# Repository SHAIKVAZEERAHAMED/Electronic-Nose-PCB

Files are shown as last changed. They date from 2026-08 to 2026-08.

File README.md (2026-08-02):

# Electronic Nose System

A compact 14-channel MEMS-based Electronic Nose (E-Nose) platform designed for multi-gas sensing applications. The system integrates analog signal acquisition, dual-microcontroller processing, heater control, and battery-powered operation on a custom-designed PCB developed using KiCad.

---

## Overview

The Electronic Nose System is a modular hardware platform designed to interface with fourteen MEMS gas sensors for detecting a wide range of volatile organic compounds (VOCs) and hazardous gases. The design combines dedicated analog front-end circuits, a dual-microcontroller architecture, and an efficient power management subsystem into a compact printed circuit board.

The project focuses on hardware architecture, PCB implementation, and modular subsystem design to support future gas classification and pattern recognition algorithms.

---

## Key Features

- 14-channel MEMS gas sensor array
- ESP32-S3 WROOM 1 N16 main controller
- RP2040 dedicated PWM co-processor
- Configurable analog front-end
- Battery-powered operation
- Dual heater voltage rails (1.8 V and 2.5 V)
- BME680 environmental sensing
- KiCad 9.0.7 PCB design
- Modular hardware architecture

---

## System Architecture

```text
                    +----------------------+
                    |   MEMS Gas Sensors   |
                    +----------+-----------+
                               |
                               v
                    +----------------------+
                    |  Analog Front End    |
                    +----------+-----------+
                               ^
                               |
                              SPI
                               |
                               v
                    +----------------------+
                    |   ESP32-S3 (Master)  |
                    +----+--+---------+----+
                         |  ^         |
                         |  |         |
                      UART SPI       I²C/ADC
                         |  |         |
                         v  v         v
                  +--------------+  BME680
                  |    RP2040    |
                  +------+-------+
                         |
                         v
                +------------------+
                |  Heater Driver   |
                +--------+---------+
                         |
                         v
                +------------------+
                |  MEMS Heaters    |
                +------------------+

          Power Management supplies all modules
```

<p align="center">
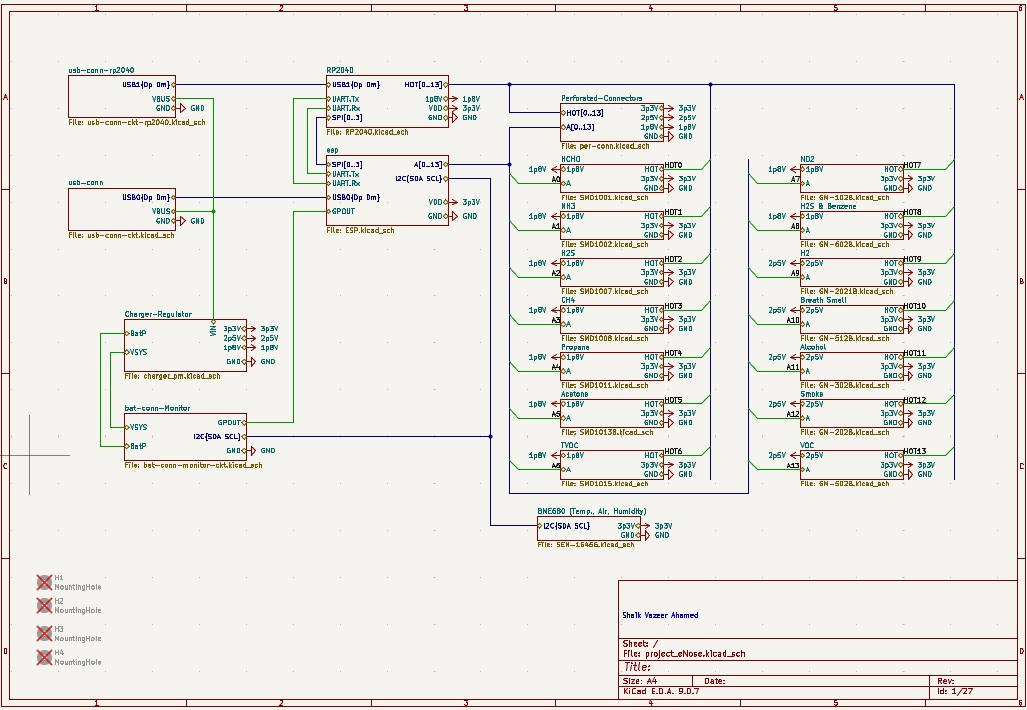
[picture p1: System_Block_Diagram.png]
  
</p>
---
---

## PCB Layout

### Top View

<p align="center">
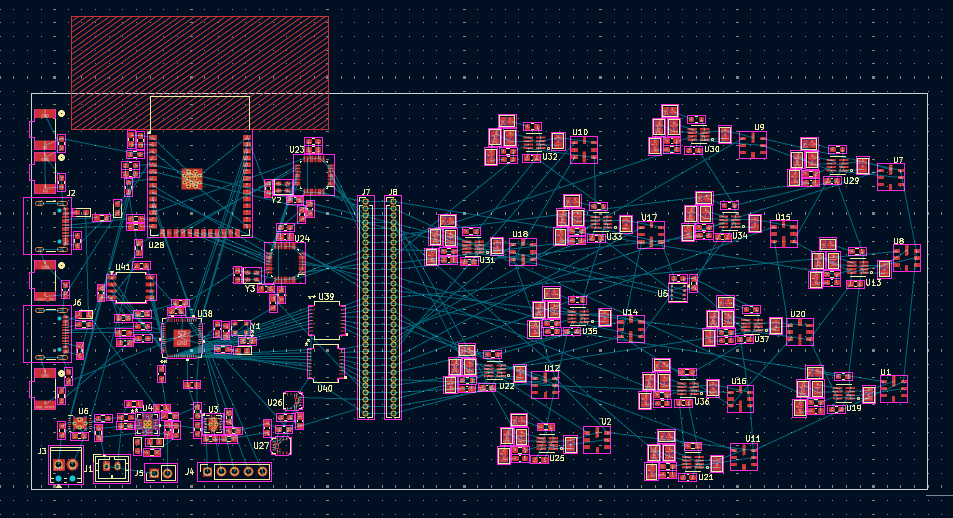
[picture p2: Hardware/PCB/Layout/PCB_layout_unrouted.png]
  
</p>

### 3D View

<p align="center">
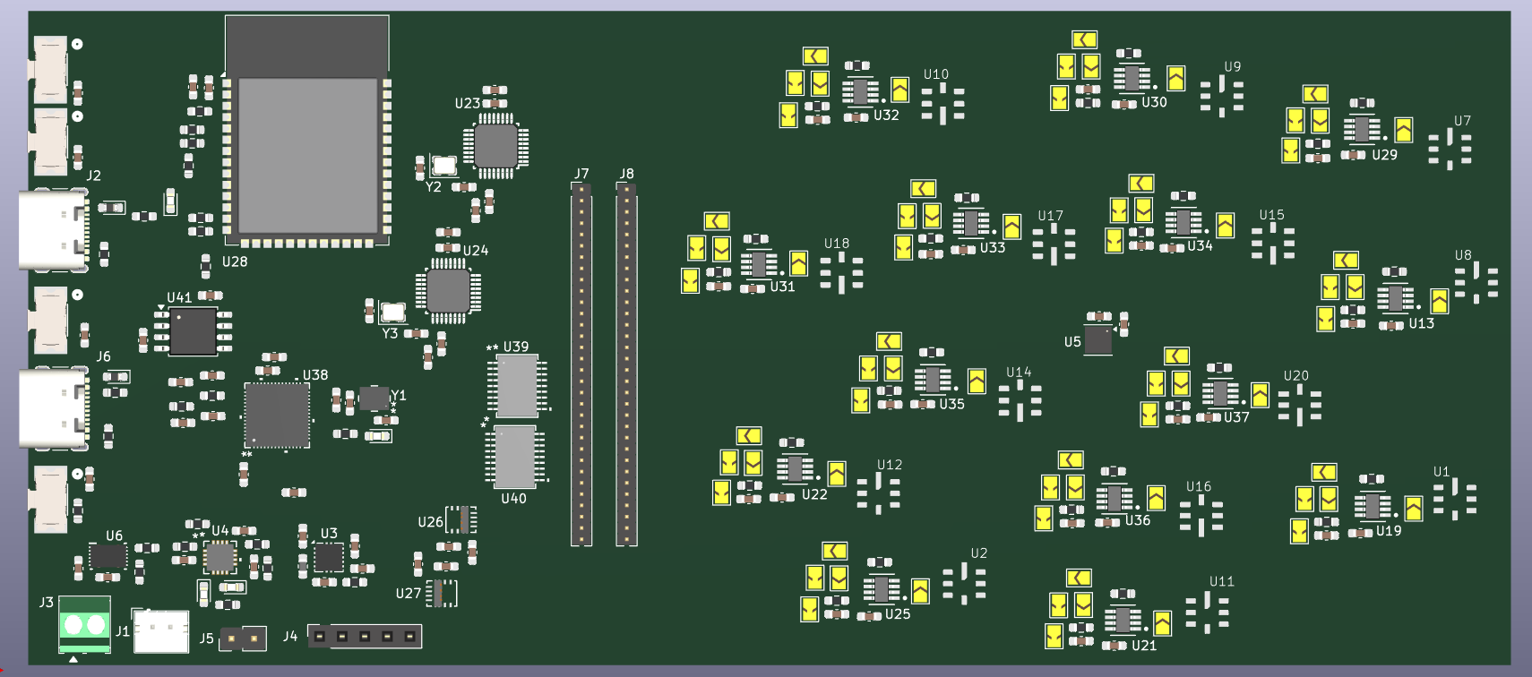
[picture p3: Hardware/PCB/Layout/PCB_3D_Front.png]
  
</p>

<p align="center">
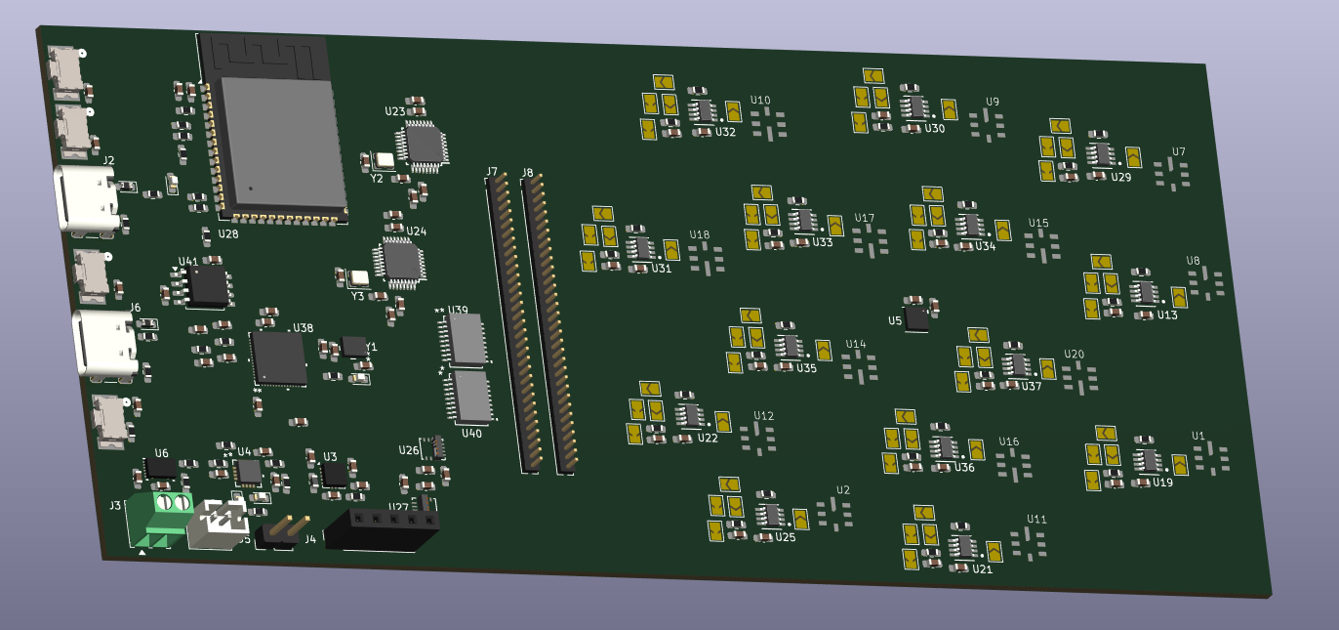
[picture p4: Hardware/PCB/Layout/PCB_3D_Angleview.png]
  
</p>

---

## Hardware Specifications

| Component | Description |
|---|---|
| Gas Sensors | 14 MEMS Gas Sensors |
| Main Controller | ESP32-S3 WROOM 1 N16 |
| PWM Controller | RP2040 |
| Heater Driver | TBD62083AFNG |
| Environmental Sensor | BME680 |
| Analog Front End | TLV9152 |
| PCB Software | KiCad 9.0.7 |
| Power Source | Rechargeable Li-ion Battery |

---

## Repository Structure

```text
Electronic-Nose-PCB
│
├── Hardware
│   ├── Sensors
│   ├── Analog_Front_End
│   ├── ESP32-S3
│   ├── RP2040
│   ├── Power_Management
│   ├── PCB
│   └── KiCad_Project
│
├── Documentation
├── Datasheets
└── README.md
```
---

## Hardware

The hardware design is divided into modular subsystems:

- MEMS Gas Sensor Array
- Analog Front-End
- ESP32-S3 Processing Unit
- RP2040 PWM Controller
- Heater Driver
- Battery Management
- PCB Layout

---

## Software

| Tool | Purpose |
|---|---|
| KiCad 9.0.7 | PCB Design |
| GitHub | Version Control |

---

## Project Status

🚧 Under Development

Current progress:

- ✅ System Architecture
- ✅ Schematic Design
- ⏳ PCB Layout
- ⏳ PCB Fabrication
- ⏳ Hardware Testing
- ⏳ Firmware Development

---

## License

This project is intended for academic and research purposes.

---

## Acknowledgment

This work was carried out at the International Institute of Information Technology Bangalore (IIIT Bangalore) under the guidance of Prof. Kurian Polachan. Technical guidance and discussions from Prof. David Aleklett Kadish and David Cuartielles (Malmö University and Arduino Co-founder) are gratefully acknowledged.

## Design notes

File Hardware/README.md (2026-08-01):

# Hardware

This directory contains the complete hardware design of the Electronic Nose PCB.

The hardware is organized into functional subsystems to simplify design, development, testing, and future maintenance.

## Hardware Organization

| Folder | Description |
|---|---|
| Sensors | MEMS gas sensor array and sensor interface |
| Analog_Front_End | Signal conditioning circuits including RC filters and operational amplifiers |
| ESP32-S3 | Main controller responsible for sensor acquisition and communication |
| RP2040 | Dedicated PWM controller for MEMS heater control |
| Power_Management | Battery charger, fuel gauge, voltage regulators, and power distribution |
| PCB | PCB layouts, fabrication outputs, and 3D models |
| KiCad_Project | Complete KiCad project files |

## Design Software

- KiCad 9.0.7

## Hardware Overview

The Electronic Nose PCB integrates a fourteen-channel MEMS gas sensor array, analog front-end circuits, dual microcontrollers (ESP32-S3 and RP2040), and a dedicated power management subsystem into a compact modular platform.

Each subsystem is documented separately within its respective directory.

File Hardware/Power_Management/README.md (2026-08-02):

# Power Management

This directory contains the power management circuitry of the Electronic Nose hardware.

## Overview

The power management subsystem supplies regulated voltages to the analog, digital, and sensor heater circuits. It is designed to support battery-powered operation while providing stable and efficient power distribution across the entire system.

## Main Functions

- Battery charging
- Battery voltage monitoring
- Fuel gauging
- Voltage regulation
- Power distribution

## Power Architecture

The system operates from a rechargeable lithium-ion battery. Dedicated power management circuits generate multiple regulated voltage rails required by the different subsystems.

| Voltage Rail | Purpose |
|---|---|
| 3.3 V | ESP32-S3, RP2040, BME680, analog circuitry |
| 2.5 V | MEMS sensor heaters |
| 1.8 V | MEMS sensor heaters |

## Main Components

| Component | Function |
|---|---|
| Battery Charger IC | Battery charging |
| Fuel Gauge IC | Battery monitoring |
| Buck Converter | 2.5 V supply |
| Buck Converter | 1.8 V supply |
| Buck Boost Converter | 3.3 V supply |

### Per-rail power summary

| Rail | Sensors | Peak current (all on) | Max heater power |
|---|---|---|---|
| 1.8 V | 9 | ~179 mA | ≤ 321 mW |
| 2.5 V | 5 | ~100 mA | ≤ 250 mW |
| **Total** | **14** | | **≤ 571 mW** |

Peak current and power figures are calculated from the rated maximum heater power at the rail voltage (I = P_max / V_rail). Actual in-use power will be lower, as not all sensors will be active simultaneously during temperature modulation sequences, and most sensors draw less than their rated maximum.

---

## Why Two Voltage Rails Are Required

All sensors in this array are MEMS resistive hot-plate sensors. Their heater elements are calibrated at a specific voltage which sets the hot-plate operating temperature, and therefore the sensitivity profile of the sensing material. Running a sensor at the wrong heater voltage shifts its operating temperature, degrading both sensitivity and cross-selectivity characteristics.

### Why not run all sensors from a single rail with PWM?

A common simplification is to power all sensors from the higher 2.5 V rail and use PWM with a lower duty cycle to reduce the effective drive for the 1.8 V sensors. This does not work correctly for resistive heaters, for the following reason.

A resistive heater responds to **average power**, not average voltage. Average power is proportional to V²:

```
P = V_rms² / R
```

With PWM at duty cycle D from a 2.5 V source:

```
V_avg = 2.5 × D
V_rms = 2.5 × √D
P_avg = (2.5)² × D / R
```

To set `V_avg = 1.8 V`, you need `D = 1.8 / 2.5 = 72%`. But this gives:

```
V_rms = 2.5 × √0.72 = 2.12 V
P_avg ∝ (2.12)² = 4.49   (vs 1.8² = 3.24 for true 1.8 V DC)
```

The heater would receive **38% more power** than intended, running significantly hotter than specified. To match the power of a 1.8 V DC supply, the duty cycle must be set to:

```
D = (1.8 / 2.5)² = 51.8%
```

— which gives a mean voltage of only ~1.3 V, not 1.8 V. The "average voltage = rated voltage" shortcut is incorrect for resistive loads.

Additionally, sensors in both groups prohibit exceeding 120 mW heater dissipation. With heater resistance tolerance of 60–100 Ω and 2.5 V applied during PWM ON-phases, instantaneous power can approach 104 mW — uncomfortably close to the limit with no margin for component variation.

Two separate regulated voltage rails eliminate this ambiguity and ensure each sensor operates within its characterised, calibrated conditions.

---

## Why Buck Converters at This Scale

### The efficiency argument is significant across ~570 mW of heater load

With a total heater load of ~571 mW, LDO losses from a 3.3 V input rail would be substantial:

| Rail | LDO efficiency (from 3.3 V) | Wasted power |
|---|---|---|
| 1.8 V (321 mW load) | 55% | ~262 mW wasted |
| 2.5 V (250 mW load) | 76% | ~79 mW wasted |

Total LDO waste would be ~341 mW — more than half the useful heater power, dissipated as heat on the PCB. Buck converters operating at 85–90% efficiency reduce total waste to roughly **60–85 mW**, a saving of ~260 mW.

### Thermal contamination of measurements

The wasted regulator power does not simply reduce battery runtime — it heats the PCB. All sensors in this array show strong temperature dependence: the Winsen GM-series datasheets show Rs/Rs₀ varying by factors of 2–3 across -20 °C to +50 °C. Heat dissipated by voltage regulators near the sensor array introduces a temperature offset and drift into all measurements. Buck converters, being far more efficient, dissipate far less heat locally.

## Design Considerations

- Independent power rails for digital and heater circuits
- Stable voltage supply for analog measurements
- Efficient battery-powered operation
- Low-noise power distribution
- Proper decoupling capacitors near integrated circuits

## Folder Contents

This folder will contain:

- Power management schematic
- Battery charger circuit
- Fuel gauge circuit
- Buck converter circuits

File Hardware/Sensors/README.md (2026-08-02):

# MEMS Gas Sensors

This directory contains the MEMS gas sensor array used in the Electronic Nose system.

## Overview

The Electronic Nose employs a fourteen-channel MEMS-based gas sensor array to detect a broad range of volatile organic compounds (VOCs) and hazardous gases. The sensors were selected to provide diverse sensing characteristics, enabling improved gas discrimination through pattern recognition techniques.

## Sensor Inventory and Rail Assignments

All 14 sensors, their heater voltages, maximum heater power, and assigned rails are listed below.

| Sensor | Manufacturer | Target gas | V_H | P_H (max) | Rail |
|---|---|---|-----|---|---|
| GM-102B | Winsen | NO₂ | 1.8 V ±0.1 V | ≤ 40 mW | 1.8 V |
| SMD1001 | IDM/Huiwen | Formaldehyde | 1.8 V ±0.05 V | ≤ 36 mW | 1.8 V |
| SMD1002 | IDM/Huiwen | Ammonia (NH₃) | 1.8 V ±0.05 V | ≤ 36 mW | 1.8 V |
| SMD1007 | IDM/Huiwen | Hydrogen sulfide (H₂S) | 1.8 V ±0.05 V | ≤ 36 mW | 1.8 V |
| SMD1008 | IDM/Huiwen | Methane (CH₄) | 1.8 V ±0.05 V | ≤ 30 mW | 1.8 V |
| SMD1011 | IDM/Huiwen | Propane (C₃H₈) | 1.8 V ±0.05 V | ≤ 30 mW | 1.8 V |
| SMD1013B | IDM/Huiwen | TVOC | 1.8 V ±0.1 V | ≤ 43 mW | 1.8 V |
| SMD1015 | IDM/Huiwen | Acetone | 1.8 V ±0.1 V | ≤ 30 mW | 1.8 V |
| GM-602B | Winsen | H₂S & benzene | 1.9 V ±0.1 V | ≤ 40 mW | 1.8 V† |
| GM-202B | Winsen | Smoke/alcohol | 2.5 V ±0.1 V | ≤ 50 mW | 2.5 V |
| GM-302B | Winsen | Ethanol | 2.5 V ±0.1 V | ≤ 50 mW | 2.5 V |
| GM-502B | Winsen | VOC | 2.5 V ±0.1 V | ≤ 50 mW | 2.5 V |
| GM-512B | Winsen | H₂S/alcohol/acetone | 2.5 V ±0.1 V | ≤ 50 mW | 2.5 V |
| GMV-2021B | Winsen | Hydrogen (H₂) | 2.5 V ±0.1 V | ≤ 50 mW | 2.5 V |

**†** The GM-602B is rated 1.9 V ±0.1 V, giving an operating range of 1.8 V to 2.0 V. Running it at 1.8 V places it at the lower bound of its specified tolerance. Heater power will be slightly less than at the 1.9 V nominal (by a factor of (1.8/1.9)² ≈ 90%), which is conservative and within the ≤ 40 mW limit. Sensitivity curves in the GM-602B datasheet are characterised at 1.9 V; response function will be marginally different at 1.8 V but the sensor is not damaged or out-of-spec. This grouping avoids the need for a dedicated third rail.

## Features

- Fourteen MEMS gas sensors
- Two independent heater voltage rails (1.8 V and 2.5 V)
- Individual analog output for each sensor
- PWM-based heater control through the RP2040

## Folder Contents

This folder will contain:

- Sensor schematics
- Sensor placement diagrams
- PCB images
- Sensor documentation

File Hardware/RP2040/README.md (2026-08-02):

# RP2040

This directory contains the RP2040 subsystem used in the Electronic Nose hardware.

## Overview

The RP2040 serves as a dedicated co-processor responsible for generating high-frequency PWM signals for independent control of the MEMS gas sensor heaters. Offloading PWM generation from the ESP32-S3 reduces computational overhead while providing precise timing and accurate heater control. The generated PWM signals are applied to a DMOS driver, which supplies the required current to the sensor heaters.

## Main Responsibilities

- High-frequency PWM generation
- Independent heater control
- Communication with the ESP32-S3 through UART
- Control of the TBD62083AFNG DMOS driver

## Heater Control

Each MEMS gas sensor incorporates an integrated micro-heater that requires controlled power to achieve the desired operating temperature. The RP2040 generates configurable PWM signals, which are routed to the **TBD62083AFNG DMOS driver**. The DMOS driver provides the necessary current-driving capability to switch the heater supply, enabling reliable and efficient heater operation.

## Interfaces

| Interface | Connected Device |
|---|---|
| UART & SPI | ESP32-S3 |
| GPIO | TBD62083AFNG DMOS Driver |
| PWM | MEMS Sensor Heaters (via DMOS Driver) |

## Features

- Dual-core ARM Cortex-M0+ processor
- Hardware PWM peripherals
- Precise timing generation
- Low-power operation
- Independent heater control

## Design Rationale

The RP2040 was selected because it provides multiple hardware PWM channels with accurate timing, making it well suited for controlling the MEMS sensor heaters. Since the RP2040 GPIOs cannot directly drive the heater load, the PWM outputs (10 KHz frequency) are interfaced with the **TBD62083AFNG DMOS driver**, which provides the required current-driving capability for the heater circuits. Separating heater control from the primary processing tasks improves overall system performance and allows the ESP32-S3 to focus on sensor acquisition, communication, and system management.

## Signal Flow

```text
ESP32-S3
     │
   UART
     │
     ▼
RP2040
     │
   PWM Outputs
     │
     ▼
TBD62083AFNG
DMOS Driver
     │
     ▼
MEMS Sensor Heaters
```

## Components

| Component | Description |
|---|---|
| RP2040 | PWM co-processor |
| TBD62083AFNG | 8-channel DMOS sink driver |
| UART | Communication with ESP32-S3 |
| PWM Outputs | Heater control signals |

## Folder Contents

This folder contains:

- RP2040 schematic
- UART interface
- PWM generation circuit
- DMOS driver interface

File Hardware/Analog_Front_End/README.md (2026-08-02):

# Analog Front End

This directory contains the analog front-end circuitry used to interface the MEMS gas sensors with the data acquisition system of the Electronic Nose.

## Overview

Each MEMS gas sensor produces an analog voltage proportional to the detected gas concentration. Before digitization, the sensor output passes through an analog front-end designed to improve signal quality, provide configurable amplification, and ensure accurate analog-to-digital conversion.

The analog front-end consists of:

- RC low-pass filter
- TLV9152 rail-to-rail operational amplifier
- Configurable gain selection using solder jumpers
- ADS131M08 multi-channel Analog-to-Digital Converter (ADC)
- SPI interface to the ESP32-S3

## Low-Pass Filter

A first-order RC low-pass filter with a cutoff frequency of approximately **7 kHz** is used to suppress high-frequency noise before amplification and digitization.

## Operational Amplifier

The TLV9152 operational amplifier supports two operating modes:

### Voltage Follower

- Unity gain
- High input impedance
- Low output impedance

### Non-Inverting Amplifier

- Gain selectable using Registers
- Suitable for low-level sensor signals

The low output impedance of the amplifier minimizes signal degradation caused by long PCB traces and provides a stable input to the ADC.

## Analog-to-Digital Conversion

The conditioned analog outputs from the gas sensors are sampled using the **ADS131M08**, an eight-channel, high-resolution analog-to-digital converter. The external ADC provides improved measurement accuracy and lower noise compared with the ESP32-S3 internal ADC. Digitized sensor data are transferred to the ESP32-S3 through the SPI interface for further processing.

## Signal Flow

```text
MEMS Gas Sensor
        │
        ▼
RC Low-Pass Filter (7 kHz)
        │
        ▼
TLV9152 Operational Amplifier
        │
        ▼
Gain Selection Jumpers
        │
        ▼
ADS131M08 ADC
        │
      SPI Bus
        │
        ▼
ESP32-S3
```

## Components

| Component | Description |
|---|---|
| TLV9152 | Rail-to-rail operational amplifier |
| RC Network | 7 kHz low-pass filter |
| Solder Jumpers | Gain configuration |
| ADS131M08 | 24-bit multi-channel ADC |
| SPI Interface | Communication between ADC and ESP32-S3 |

## Folder Contents

This folder contains:

- Analog front-end schematics
- ADC interface circuit

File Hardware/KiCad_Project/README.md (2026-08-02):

# KiCad Project

This directory contains the complete KiCad project files for the Electronic Nose hardware.

## Overview

The Electronic Nose PCB was designed using **KiCad 9.0.7**. This folder includes all project files required to open, edit, verify, and manufacture the PCB.

## Software Version

- KiCad 9.0.7

## Project Files

| File | Description |
|---|---|
| *.kicad_pro | KiCad project file |
| *.kicad_sch | Complete schematic |
| *.kicad_pcb | PCB layout |

## Design Features

- Multi-sheet schematic
- Fourteen-channel MEMS gas sensor array
- Dual microcontroller architecture
- Analog front-end circuitry
- Power management subsystem
- Single-layer PCB layout
- Design Rule Check (DRC) in progress
- Electrical Rule Check (ERC) verified

## How to Open

1. Install **KiCad 9.0.7** or later.
2. Open the `.kicad_pro` file.
3. Use the Schematic Editor to view the circuit design.
4. Use the PCB Editor to inspect or modify the layout.

## Folder Contents

This folder will contain:

- KiCad project
- Schematics
- PCB layout

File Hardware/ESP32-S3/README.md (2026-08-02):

# ESP32-S3

This directory contains the ESP32-S3 subsystem of the Electronic Nose hardware.

## Overview

The ESP32-S3 serves as the primary processing unit of the Electronic Nose system. It is responsible for acquiring sensor data, communicating with peripheral devices, and coordinating the overall operation of the system.

## Main Responsibilities

- Acquisition of analog signals from the MEMS gas sensors
- Communication with the RP2040 through UART and SPI
- Communication with the BME680 environmental sensor through I²C
- Battery monitoring
- System control and coordination
- Wireless communication (Wi-Fi / Bluetooth)

## Interfaces

| Interface | Connected Device |
|---|---|
| ADC | Analog Front End |
| UART | RP2040 |
| SPI | RP2040 |
| I²C | BME680 |
| GPIO | System peripherals |

## Features

- Dual-core Xtensa LX7 processor
- Integrated Wi-Fi and Bluetooth
- Multiple ADC channels
- UART, SPI, and I²C interfaces
- Low-power operation

## Folder Contents

This folder will contain:

- ESP32-S3 schematic
- Circuit diagrams

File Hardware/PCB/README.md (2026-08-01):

# Printed Circuit Board (PCB)

This directory contains the PCB layout, fabrication outputs, and mechanical design of the Electronic Nose system.

## Overview

The Electronic Nose hardware was implemented as a compact printed circuit board (PCB) designed using KiCad 9.0.7. The layout integrates the MEMS gas sensor array, analog front-end circuits, processing units, heater control circuitry, and power management subsystem into a single modular platform.

## PCB Features

- Compact PCB layout
- Fourteen-channel MEMS gas sensor array
- Modular subsystem placement
- Battery-powered operation
- Dedicated analog and digital sections
- Detachable sensor board
- Design optimized for future expansion

## PCB Design Considerations

The PCB layout was designed with emphasis on:

- Functional component grouping
- Short analog signal paths
- Efficient power distribution
- Stable ground connections
- Heater and signal isolation
- Manufacturability

## Board Contents

The PCB includes the following functional blocks:

- MEMS Gas Sensor Array
- Analog Front End
- ESP32-S3 Controller
- RP2040 PWM Controller
- Heater Driver
- Power Management
- Environmental Sensor

## Folder Contents

This folder will contain:

- PCB Top View
- PCB Bottom View
- 3D PCB Model
- Gerber Files
- Drill Files
- Manufacturing Outputs
- Assembly Drawings

## Directory Structure

```text
PCB/
├── Layout/
├── Gerbers/
├── Manufacturing/
```

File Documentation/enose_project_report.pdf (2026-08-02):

# Design and PCB Implementation of an Electronic Nose System

Shaik Vazeer Ahamed
Department of Electronics and Communication Engineering International Institute of Information Technology Bangalore Email: Shaik.Ahamed@iiitb.ac.in

Abstract—Electronic nose (e-nose) systems have gained significant attention for applications in environmental monitoring, industrial safety, healthcare, and food quality assessment due to their ability to detect and distinguish multiple gases. This paper presents the design and printed circuit board (PCB) implementation of a compact electronic nose system integrating a fourteen-channel gas sensor array with analog signal conditioning, power management, and embedded processing. The hardware architecture employs an ESP32-S3 microcontroller for system control and wireless communication, while an RP2040 microcontroller is incorporated to generate high-frequency pulse-width modulation (PWM) signals for independent sensor heater control. Dedicated analog front-end circuits were designed to condition the sensor outputs before data acquisition. A rechargeable battery management subsystem, multiple regulated power rails, and environmental sensing were integrated to enable reliable standalone operation. The PCB was designed using KiCad

### 9.0.7 with careful consideration of component placement, power

distribution, ground plane implementation, thermal management, and a detachable perforated sensor board to facilitate sensor replacement and future upgrades. The developed hardware provides a compact and modular platform suitable for multigas sensing applications and serves as a foundation for future gas identification and pattern recognition algorithms.
Index Terms—Electronic Nose, Gas Sensors, PCB Design, ESP32-S3, RP2040, Signal Conditioning, KiCad 9.0.7
I. INTRODUCTION
Electronic nose (e-nose) systems have emerged as an effective technology for detecting and distinguishing volatile compounds by employing an array of gas sensors combined with signal processing techniques. Unlike conventional gas detection systems that are designed to identify a single target gas, electronic noses utilize the collective response of multiple sensors to generate characteristic patterns for different gaseous environments. Owing to their versatility, e-nose systems have been widely investigated for applications including environmental monitoring, industrial safety, food quality assessment, agricultural monitoring, and healthcare diagnostics [1]–[3]. Recent advancements in low-power embedded systems and gas sensing technologies have enabled the development of compact and portable electronic nose platforms. In particular, temperature modulation and fast heater cycling have been shown to improve the selectivity and gas discrimination capability of MEMS metal-oxide gas sensors [1]–[3]. However, the integration of multiple gas sensors with their associated analog front-end circuits, heater control, power management, and embedded processing remains a significant hardware design challenge. Variations in sensor operating conditions, analog signal integrity, power distribution, and thermal effects must be carefully considered during both schematic development and printed circuit board (PCB) layout to ensure reliable system operation.
This work presents the design and PCB implementation of a compact electronic nose system capable of supporting a fourteen-channel gas sensor array. The proposed hardware integrates analog signal conditioning circuits, dedicated heater control, battery management, environmental sensing, and dual microcontroller architecture using the ESP32-S3 and RP2040. The system architecture was designed to provide modularity, efficient power distribution, and simplified sensor integration while maintaining a compact PCB layout suitable for standalone operation.
The PCB was developed using KiCad 9.0.7 with emphasis on component placement, power and ground distribution, thermal management, and the implementation of a detachable perforated sensor board to facilitate sensor replacement and future hardware expansion. The resulting hardware platform provides a flexible foundation for the development of electronic nose applications involving multi-gas sensing and subsequent pattern recognition.
The remainder of this paper is organized as follows. Section II presents the overall system architecture. Section III describes the hardware design, including the gas sensor array, analog signal conditioning circuits, processing units, and power management subsystem. Section IV discusses the PCB layout design and implementation. Section V presents the implementation results and design verification, while Section VI concludes the paper.

II. SYSTEM OVERVIEW

A. Overall System Architecture
Figure 1 illustrates the overall architecture of the proposed electronic nose system. The system integrates a fourteen-channel gas sensor array, analog signal conditioning circuits, dual microcontrollers, power management circuitry, and an environmental sensor on a custom-designed printed circuit board (PCB). The modular architecture was developed to provide reliable sensor interfacing, efficient power distribution, and simplified hardware integration.
The gas sensor array consists of fourteen MEMS-based gas sensors, each interfaced with an analog signal conditioning


Fig. 1: Overall system architecture.

circuit. The conditioned analog signals from the fourteen MEMS gas sensors are digitized using the ADS131M08 multi-channel analog-to-digital converter (ADC). The digitized sensor data are transferred to the ESP32-S3 through the SPI interface for further processing and wireless communication. An RP2040 microcontroller is incorporated as a dedicated co-processor to generate high-frequency pulse-width modulation (PWM) signals required for independent heater control of the gas sensors. Communication between the two controllers is achieved through standard digital communication interfaces. The power management subsystem includes a rechargeable battery, battery charging circuit, fuel gauge, and multiple regulated voltage rails to supply the various analog and digital components. In addition, a BME680 environmental sensor is integrated to monitor ambient temperature, humidity, and pressure, enabling environmental compensation during gas sensing. A detachable perforated sensor board is employed to simplify sensor replacement and facilitate future hardware modifications without affecting the main processing board.

B. Overall Architecture

III. HARDWARE DESIGN

A. MEMS Gas Sensor Array

The proposed electronic nose system employs a fourteen-channel MEMS-based gas sensor array to detect a broad range of volatile organic compounds (VOCs) and hazardous gases. MEMS gas sensors were selected due to their compact size, low power consumption, fast thermal response, and improved stability compared with conventional gas sensors. Each sensor incorporates an integrated micro-heater that maintains the sensing material at the required operating temperature.
To enable selective gas detection, sensors with different sensing characteristics were incorporated into the array. The diverse sensor responses provide characteristic signal patterns that can be utilized for subsequent gas identification algorithms. Table I summarizes the gas sensors used in the proposed system and their primary target gases.

TABLE I: MEMS Gas Sensors Used in the Proposed Electronic Nose

Sensor | Target Gas | Heater Voltage
SMD1001 SMD1002 SMD1007 SMD1008 SMD1011 SMD1013B SMD1015 GM-102B GM-202B GM-2021B GM-302B GM-502B GM-512B GM-602B | HCHO NH3 H2S Combustible Gases (CH4) Propane Acetone TVOC NO2 Smoke H2 Alcohol VOC Breath Odor H2S and Benzene | 1.8 V 1.8 V 1.8 V 1.8 V 1.8 V 1.8 V 1.8 V 1.8 V 2.5 V 2.5 V 2.5 V 2.5 V 2.5 V 1.8 V

In addition to the gas sensor array, a BME680 environmental sensor was integrated to measure ambient temperature, humidity, and pressure. These environmental parameters can be used for compensation during sensor calibration and gas sensing, thereby improving measurement consistency under varying operating conditions.

B. Signal Acquisition Circuit

Each MEMS gas sensor is interfaced with an identical signal acquisition circuit to ensure consistent signal conditioning before analog-to-digital conversion. As shown in Fig. 3 and Fig. 4, the sensor output is first passed through a first-order RC low-pass filter with a cutoff frequency of approximately 7 kHz. The filter suppresses high-frequency noise while preserving the low-frequency variations in the sensor response that are relevant for gas detection.
Following the low-pass filter, the conditioned signal is buffered using a TLV9152 rail-to-rail operational amplifier. The amplifier configuration can be selected through solder jumper pads, allowing the circuit to operate either as a voltage follower (unity-gain buffer) or as a non-inverting amplifier with adjustable gain. This configurable design provides flexibility for interfacing sensors with different output voltage ranges without requiring modifications to the PCB.
The operational amplifier also serves as an impedance buffer between the sensor and the analog-to-digital converter (ADC). Its high input impedance minimizes loading of the sensor, while its low output impedance reduces signal degradation caused by long PCB traces and improves the stability of the analog signal presented to the ADS131M08 analog-to-digital converter. The conditioned analog signals are digitized by the ADS131M08 ADC and transferred to the ESP32-S3 through the SPI interface.
C. Processing and Communication

The proposed electronic nose system employs a dual-microcontroller architecture consisting of an ESP32-S3 and an RP2040 to efficiently distribute processing and control

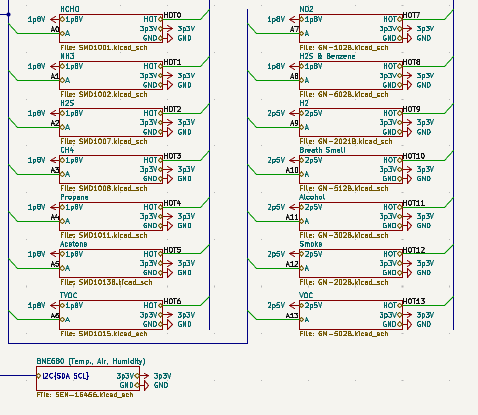
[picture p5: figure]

Fig. 2: Arrangement of the fourteen MEMS gas sensors and the BME680 environmental sensor.

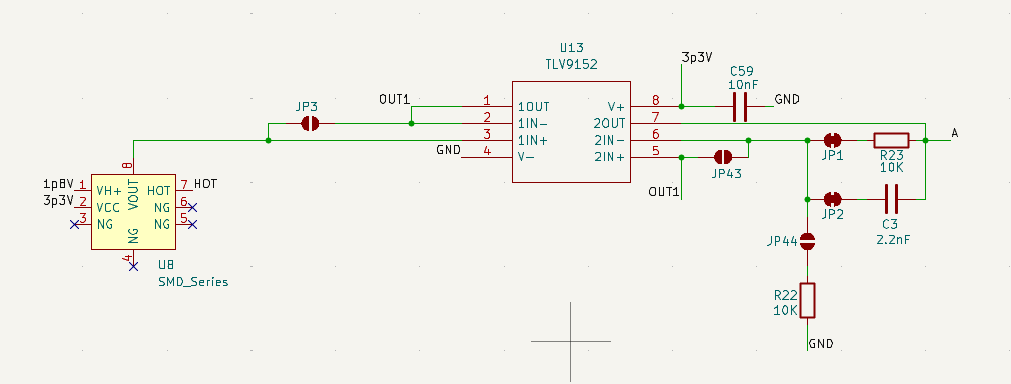
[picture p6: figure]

Fig. 3: Representative signal acquisition circuit for SMD-series MEMS gas sensors (7 Sensors).

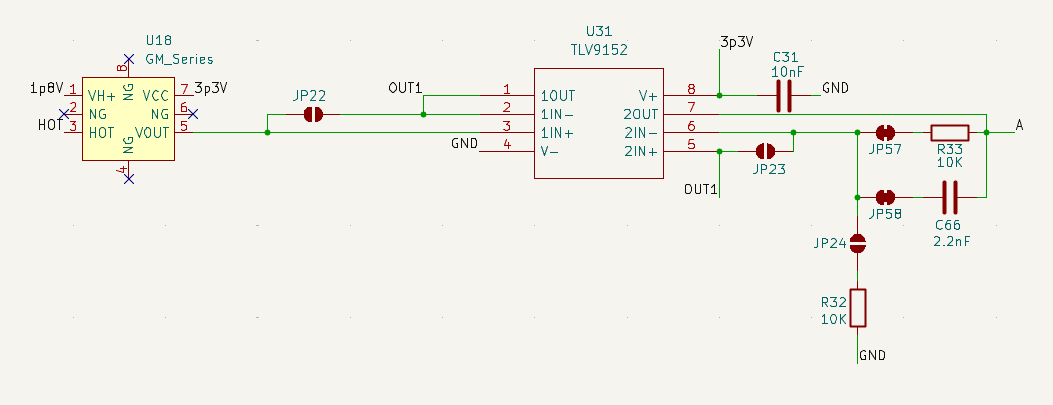
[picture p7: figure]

Fig. 4: Representative signal acquisition circuit for GM-series MEMS gas sensors (7 Sensors).

tasks. The ESP32-S3, shown in Fig. 6, serves as the primary processing unit responsible for sensor data acquisition, system control, wireless communication, and peripheral management. The conditioned analog signals from the fourteen MEMS gas sensors are digitized using the ESP32-S3 analog-to-digital converter (ADC) and processed for subsequent analysis. The RP2040 microcontroller, shown in Fig. 7, is employed as a dedicated co-processor for sensor heater control. It generates high-frequency 3.3 V pulse-width modulation (PWM) control signals, which are applied to the TBD62083AFNG

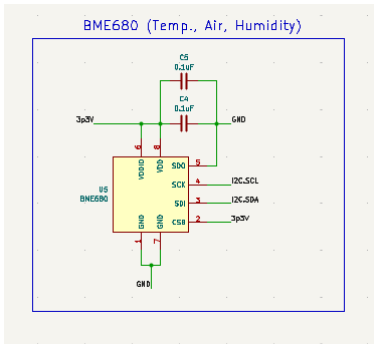
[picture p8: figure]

Fig. 5: BME680 Sensor (Pressure, Humidity, and Temperature).

DMOS transistor array. The DMOS driver provides the required current-driving capability to switch the regulated heater supply for the MEMS gas sensors while electrically isolating the microcontroller from the heater load. This dedicated architecture enables reliable heater control without increasing the computational load on the ESP32-S3.
Communication between the ESP32-S3 and RP2040 is established through a UART interface, enabling bidirectional exchange of control commands and system status information. In addition, the ESP32-S3 communicates with peripheral devices through I²C and SPI interfaces, providing support for the BME680 environmental sensor and future hardware expansion. The separation of processing and heater control tasks improves system scalability, simplifies firmware development, and enhances overall system reliability.
D. Power Management

The proposed electronic nose system is powered by a rechargeable lithium-ion battery, enabling portable and standalone operation. A battery charging integrated circuit (IC) is incorporated to support safe charging through a USB interface, while a battery fuel gauge continuously monitors the battery status by measuring parameters such as voltage, current, and remaining capacity. The battery information is communicated to the ESP32-S3, allowing the system to monitor power availability and battery health.
To meet the power requirements of the different hardware modules, dedicated buck converters and voltage regulators generate multiple regulated supply rails from the battery voltage. A 3.3 V supply powers the ESP32-S3, RP2040, BME680 environmental sensor, and other digital peripherals, while separate 2.5 V and 1.8 V supply rails are provided for

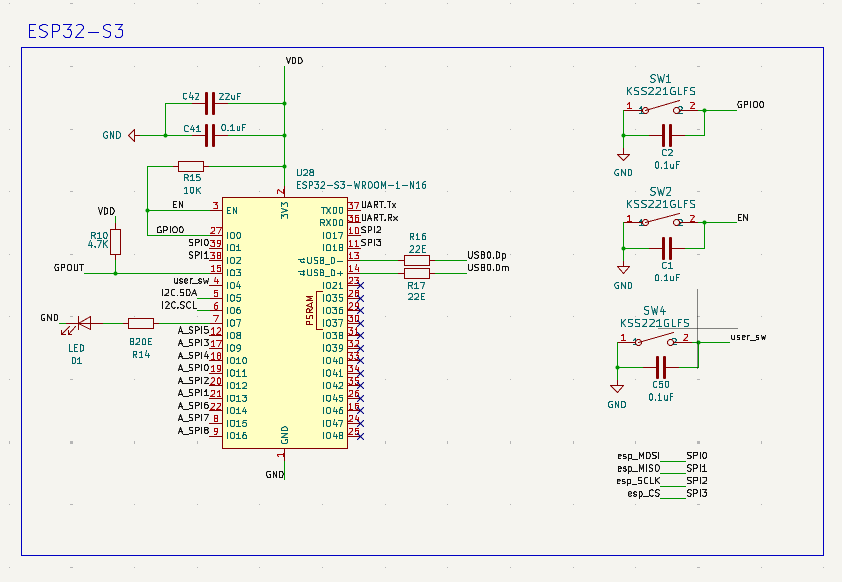
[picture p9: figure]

Fig. 6: ESP32-S3 module used as the primary processing unit.

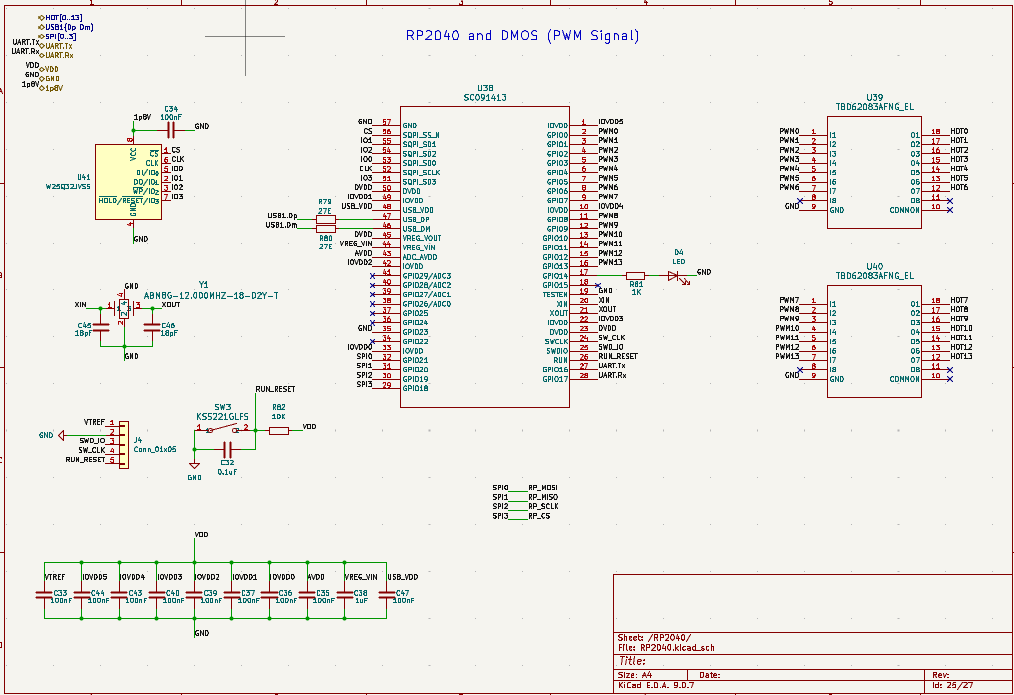
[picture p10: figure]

Fig. | 7: | RP2040 | heater-control | subsystem | with
TBD62083AFNG DMOS driver.

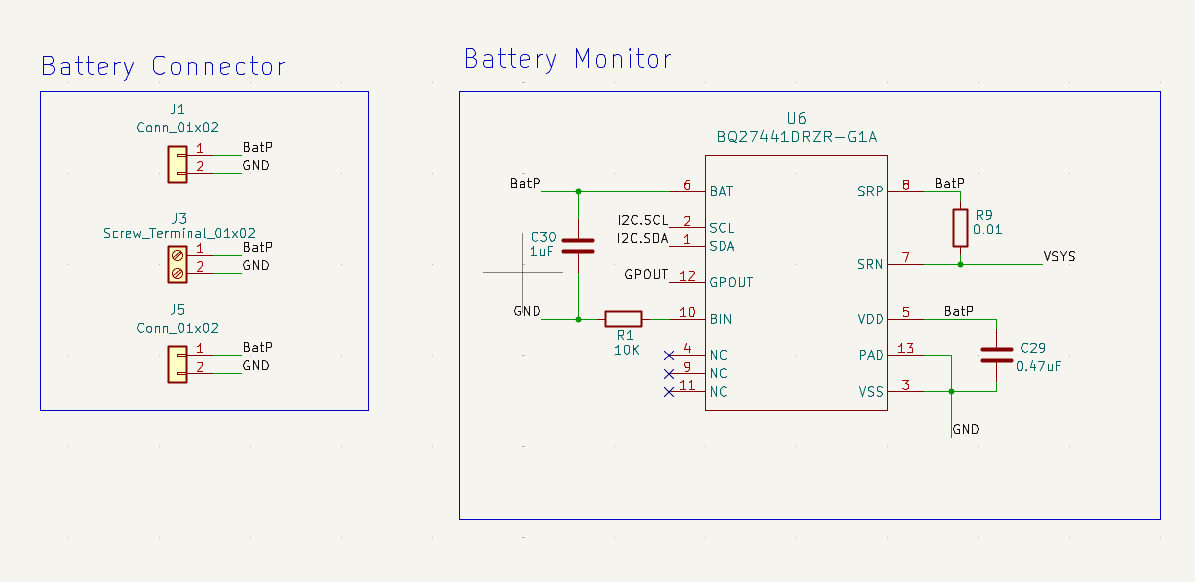
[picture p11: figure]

Fig. 8: Battery Connector and fuel gauge circuit.

the MEMS gas sensor heaters based on their operating voltage specifications. This multi-rail power architecture ensures stable operation of all subsystems while improving overall power efficiency. The battery charging circuit supports charging through a USB Type-C interface.

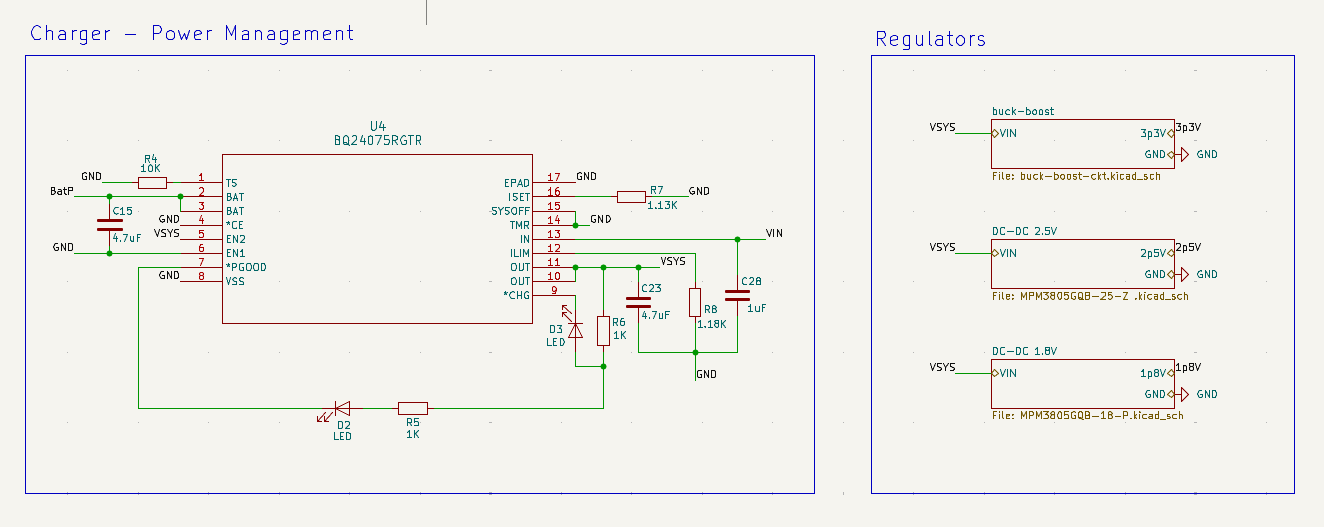
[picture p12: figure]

Fig. 9: Battery Charging and Power management circuit showing the regulated power distribution.

IV. PCB LAYOUT DESIGN

The proposed electronic nose system was implemented as a compact single-layer printed circuit board (PCB) using KiCad. The PCB integrates the sensing, signal acquisition, processing, communication, and power management circuits into a single platform while maintaining a layout that minimizes electrical noise and simplifies system assembly. Particular attention was given to component placement, power distribution, and sensor integration to ensure reliable operation of the analog and digital subsystems.

A. Component Placement
The PCB layout was designed by grouping components according to their functionality to improve signal integrity and simplify routing. The fourteen MEMS gas sensors were positioned together on one side of the PCB to facilitate installation inside the gas chamber and to ensure uniform exposure to the target gases. The signal acquisition circuits were placed close to the corresponding sensors to minimize analog trace lengths and reduce noise pickup.
The ESP32-S3 and RP2040 microcontrollers were positioned near the center of the PCB to provide efficient routing to the analog front-end, power management circuitry, and communication interfaces. Battery management components, buck converters, and other power circuits were located away from the sensitive analog circuitry to reduce electrical interference.
B. Sensor Board Integration
To simplify fabrication and future maintenance, the MEMS gas sensors were mounted on a detachable perforated sensor board connected to the main PCB. This arrangement enables straightforward sensor replacement and provides flexibility for evaluating different sensor combinations without redesigning the primary circuit board. The modular configuration also facilitates integration of the sensor array into an enclosed gas chamber while maintaining reliable electrical connections with the signal acquisition circuitry.
C. PCB Implementation
The proposed electronic nose system was implemented as a compact single-layer printed circuit board (PCB) using KiCad. Figure 10 presents the completed PCB layout, highlighting the placement of the MEMS gas sensor array,


Fig. 10: Top view of the proposed electronic nose PCB layout.

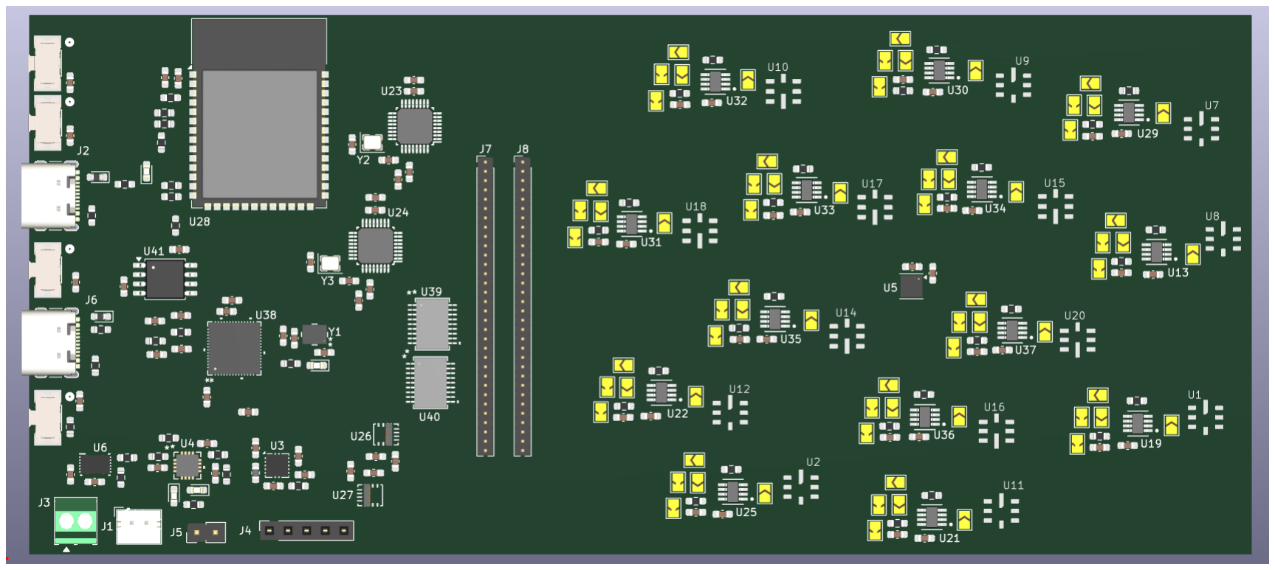
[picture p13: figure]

Fig. 11: Three-dimensional view of the proposed electronic nose PCB.

TABLE II: PCB Design Specifications

Parameter | Value
Board Size Number of Layers Processor PWM Controller Number of Sensors Environmental Sensor PCB Software Supply Voltages | 73.6 mm x 166.8 mm 1 ESP32-S3 RP2040 14 1 (BME680) KiCad 9.0.7 3.3V, 2.5V, 1.8V

signal acquisition circuits, processing units, communication interfaces, and power management circuitry. Figure 11 shows the three-dimensional rendering of the PCB, providing a visual representation of the final hardware implementation. The completed design offers a compact and modular platform suitable for future development and evaluation of electronic nose applications.

V. CONCLUSION

This paper presented the design and PCB implementation of a compact electronic nose system based on a fourteen-channel MEMS gas sensor array. The proposed hardware integrates signal acquisition circuits, a dual-microcontroller architecture consisting of an ESP32-S3 and an RP2040, and a dedicated power management subsystem into a single platform. The RP2040 provides independent PWM-based heater control through a DMOS driver, while the ESP32-S3 performs sensor data acquisition, system control, and communication. The PCB was designed using KiCad with emphasis on modularity, compact component placement, and efficient power distribution. The proposed hardware platform provides a flexible foundation for future implementation of gas classification algorithms and experimental evaluation in electronic nose applications.

ACKNOWLEDGMENT
The authors would like to express their sincere gratitude to the Department of Electronics and Communication Engineering, International Institute of Information Technology Bangalore (IIIT Bangalore), for providing the facilities and resources required to carry out this work. The authors are especially grateful to Prof. Kurian Polachan for his valuable guidance, continuous support, and constructive feedback throughout the project. The authors also acknowledge the technical guidance and insightful discussions provided by Prof. David Aleklett Kadish and David Cuartielles (Malmo University and Arduino ¨ Co-founder), which greatly contributed to the development of this work.

REFERENCES

[1] N. Dennler, J. Sommerhauser, and A. T. G ¨ | untner, “Enhancing Selec- ¨
tivity Through Fast Heater Cycles with MOx Sensors,” Proceedings of EUROSENSORS XXXVII, pp. 259–260, 2025.
[2] W. Luo, F. Dai, Y. Liu, X. Wang, and M. Li, “Pulse-driven MEMS Gas Sensor Combined with Machine Learning for Selective Gas Identification,” Microsystems & Nanoengineering, vol. 11, p. 72, 2025.
[3] H. Kim et al., “Multigas Identification by Temperature-Modulated Operation of a Single Anodic Aluminum Oxide Gas Sensor Platform and Deep Learning Algorithm,” ACS Sensors, vol. 10, no. 2, pp. 1162– 1173, 2025.

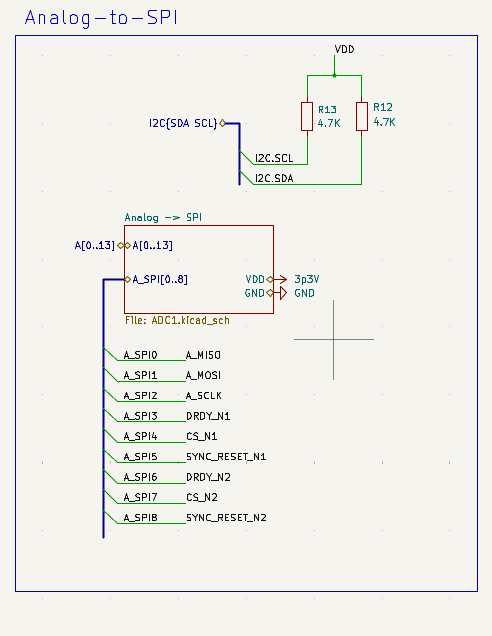
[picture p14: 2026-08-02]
Hardware/Analog_Front_End/ADC-SPI_top.png

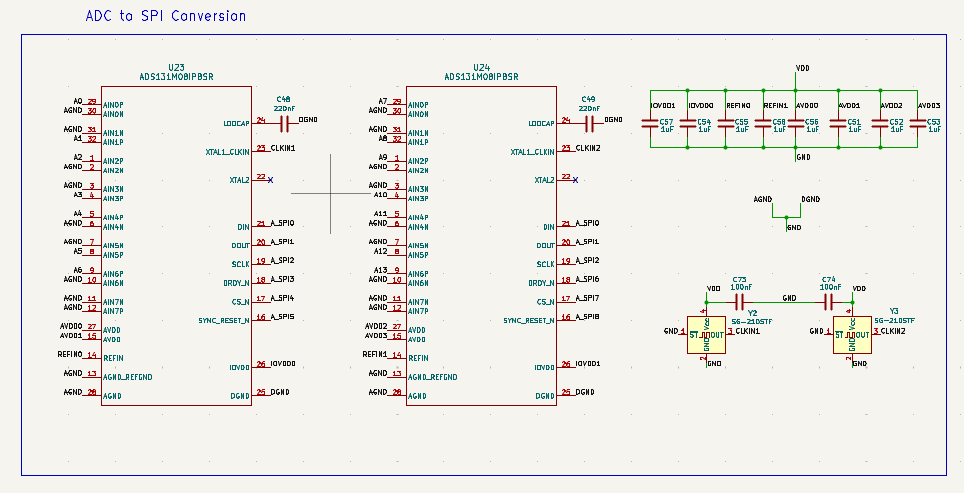
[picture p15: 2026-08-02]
Hardware/Analog_Front_End/ADC-SPI.png

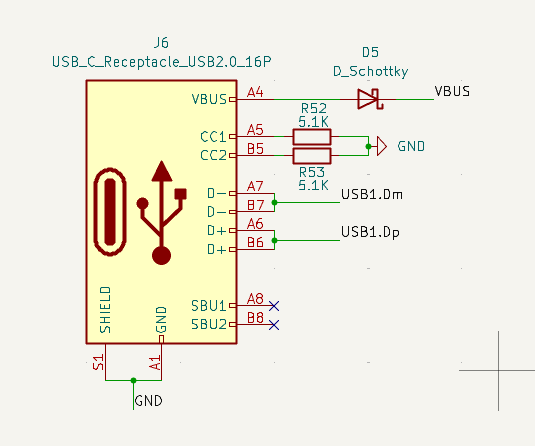
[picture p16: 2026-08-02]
Hardware/Power_Management/USB_C.png

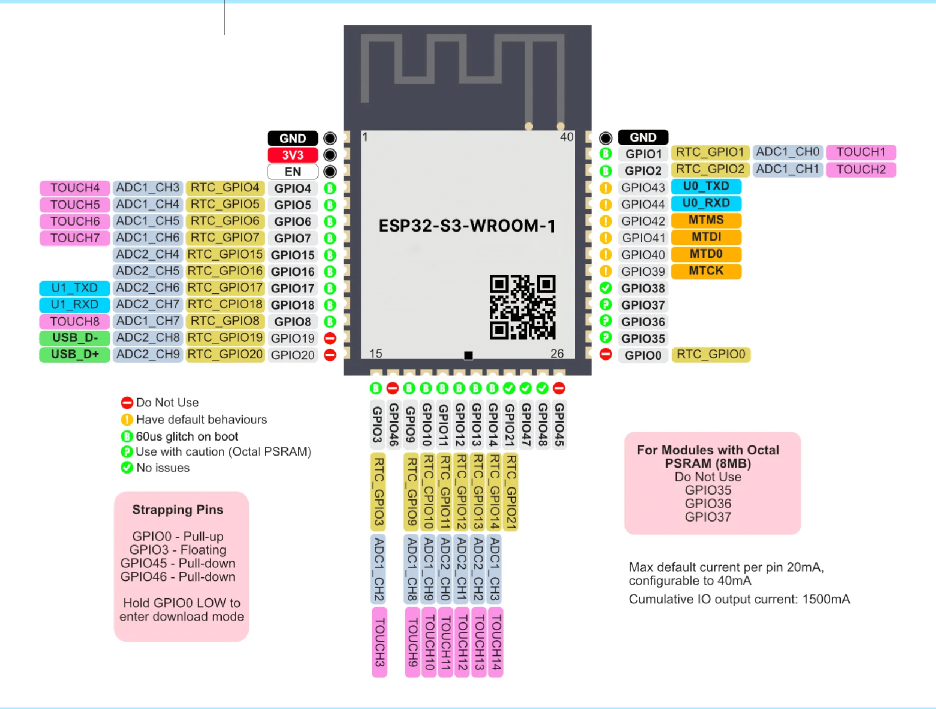
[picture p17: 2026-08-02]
Hardware/ESP32-S3/esp32_orginal.png

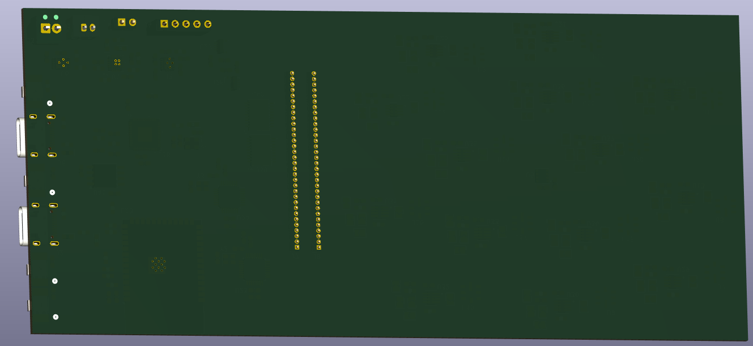
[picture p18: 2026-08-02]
Hardware/PCB/Layout/PCB_3D_backside.png

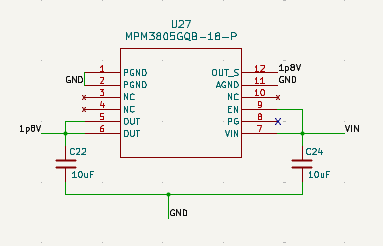
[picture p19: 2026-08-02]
Hardware/Power_Management/1p8V_buck_converter.png

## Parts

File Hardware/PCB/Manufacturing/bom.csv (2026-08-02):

Reference | Value | Footprint | myMANUFACTURER | myMPN
C1 | 0.1uF | Capacitor_SMD:C_0603_1608Metric_Pad1.08x0.95mm_HandSolder | YAGEO | CC0603MRY5V9BB104
C2 | 0.1uF | Capacitor_SMD:C_0603_1608Metric_Pad1.08x0.95mm_HandSolder | YAGEO | CC0603MRY5V9BB104
C3 | 2.2nF | Capacitor_SMD:C_0603_1608Metric_Pad1.08x0.95mm_HandSolder | KEMET | C0603X222F4HACTU
C4 | 0.1uF | Capacitor_SMD:C_0603_1608Metric_Pad1.08x0.95mm_HandSolder | YAGEO | CC0603MRY5V9BB104
C5 | 0.1uF | Capacitor_SMD:C_0603_1608Metric_Pad1.08x0.95mm_HandSolder | YAGEO | CC0603MRY5V9BB104
C6 | 10nF | Capacitor_SMD:C_0603_1608Metric_Pad1.08x0.95mm_HandSolder | Murata Electronics | GCM188R71H103KA37J
C7 | 10uF | Capacitor_SMD:C_0603_1608Metric_Pad1.08x0.95mm_HandSolder | Walsin Technology Corporation | 0603X106M100CT
C8 | 10nF | Capacitor_SMD:C_0603_1608Metric_Pad1.08x0.95mm_HandSolder | Murata Electronics | GCM188R71H103KA37J
C9 | 0.1uF | Capacitor_SMD:C_0603_1608Metric_Pad1.08x0.95mm_HandSolder | YAGEO | CC0603MRY5V9BB104
C10 | 10nF | Capacitor_SMD:C_0603_1608Metric_Pad1.08x0.95mm_HandSolder | Murata Electronics | GCM188R71H103KA37J
C11 | 10nF | Capacitor_SMD:C_0603_1608Metric_Pad1.08x0.95mm_HandSolder | Murata Electronics | GCM188R71H103KA37J
C12 | 10nF | Capacitor_SMD:C_0603_1608Metric_Pad1.08x0.95mm_HandSolder | Murata Electronics | GCM188R71H103KA37J
C13 | 10uF | Capacitor_SMD:C_0603_1608Metric_Pad1.08x0.95mm_HandSolder | Walsin Technology Corporation | 0603X106M100CT
C14 | 10uF | Capacitor_SMD:C_0603_1608Metric_Pad1.08x0.95mm_HandSolder | Walsin Technology Corporation | 0603X106M100CT
C15 | 4.7uF | Capacitor_SMD:C_0603_1608Metric_Pad1.08x0.95mm_HandSolder | YAGEO | CC0603KRX5R6BB475
C16 | 10nF | Capacitor_SMD:C_0603_1608Metric_Pad1.08x0.95mm_HandSolder | Murata Electronics | GCM188R71H103KA37J
C17 | 10nF | Capacitor_SMD:C_0603_1608Metric_Pad1.08x0.95mm_HandSolder | Murata Electronics | GCM188R71H103KA37J
C18 | 10nF | Capacitor_SMD:C_0603_1608Metric_Pad1.08x0.95mm_HandSolder | Murata Electronics | GCM188R71H103KA37J
C19 | 10nF | Capacitor_SMD:C_0603_1608Metric_Pad1.08x0.95mm_HandSolder | Murata Electronics | GCM188R71H103KA37J
C20 | 10uF | Capacitor_SMD:C_0603_1608Metric_Pad1.08x0.95mm_HandSolder | Walsin Technology Corporation | 0603X106M100CT
C21 | 10uF | Capacitor_SMD:C_0603_1608Metric_Pad1.08x0.95mm_HandSolder | Walsin Technology Corporation | 0603X106M100CT
C22 | 10uF | Capacitor_SMD:C_0603_1608Metric_Pad1.08x0.95mm_HandSolder | Walsin Technology Corporation | 0603X106M100CT
C23 | 4.7uF | Capacitor_SMD:C_0603_1608Metric_Pad1.08x0.95mm_HandSolder | YAGEO | CC0603KRX5R6BB475
C24 | 10uF | Capacitor_SMD:C_0603_1608Metric_Pad1.08x0.95mm_HandSolder | Walsin Technology Corporation | 0603X106M100CT
C25 | 10nF | Capacitor_SMD:C_0603_1608Metric_Pad1.08x0.95mm_HandSolder | Murata Electronics | GCM188R71H103KA37J
C26 | 10nF | Capacitor_SMD:C_0603_1608Metric_Pad1.08x0.95mm_HandSolder | Murata Electronics | GCM188R71H103KA37J
C27 | 10nF | Capacitor_SMD:C_0603_1608Metric_Pad1.08x0.95mm_HandSolder | Murata Electronics | GCM188R71H103KA37J
C28 | 1uF | Capacitor_SMD:C_0603_1608Metric_Pad1.08x0.95mm_HandSolder | YAGEO | CC0603KRX7R7BB105
C29 | 0.47uF | Capacitor_SMD:C_0603_1608Metric_Pad1.08x0.95mm_HandSolder | YAGEO | CC0603KRX5R8BB474
C30 | 1uF | Capacitor_SMD:C_0603_1608Metric_Pad1.08x0.95mm_HandSolder | YAGEO | CC0603KRX7R7BB105
C31 | 10nF | Capacitor_SMD:C_0603_1608Metric_Pad1.08x0.95mm_HandSolder | Murata Electronics | GCM188R71H103KA37J
C32 | 0.1uF | Capacitor_SMD:C_0603_1608Metric_Pad1.08x0.95mm_HandSolder | YAGEO | CC0603MRY5V9BB104
C33 | 100nF | Capacitor_SMD:C_0603_1608Metric_Pad1.08x0.95mm_HandSolder | YAGEO | CC0603MRX7R9BB104
C34 | 100nF | Capacitor_SMD:C_0603_1608Metric_Pad1.08x0.95mm_HandSolder | YAGEO | CC0603MRX7R9BB104
C35 | 100nF | Capacitor_SMD:C_0603_1608Metric_Pad1.08x0.95mm_HandSolder | YAGEO | CC0603MRX7R9BB104
C36 | 100nF | Capacitor_SMD:C_0603_1608Metric_Pad1.08x0.95mm_HandSolder | YAGEO | CC0603MRX7R9BB104
C37 | 100nF | Capacitor_SMD:C_0603_1608Metric_Pad1.08x0.95mm_HandSolder | YAGEO | CC0603MRX7R9BB104
C38 | 1uF | Capacitor_SMD:C_0603_1608Metric_Pad1.08x0.95mm_HandSolder | YAGEO | CC0603KRX7R7BB105
C39 | 100nF | Capacitor_SMD:C_0603_1608Metric_Pad1.08x0.95mm_HandSolder | YAGEO | CC0603MRX7R9BB104
C40 | 100nF | Capacitor_SMD:C_0603_1608Metric_Pad1.08x0.95mm_HandSolder | YAGEO | CC0603MRX7R9BB104
C41 | 0.1uF | Capacitor_SMD:C_0603_1608Metric_Pad1.08x0.95mm_HandSolder | YAGEO | CC0603MRY5V9BB104
C42 | 22uF | Capacitor_SMD:C_0603_1608Metric_Pad1.08x0.95mm_HandSolder | YAGEO | CC0603MRX5R6BB226
C43 | 100nF | Capacitor_SMD:C_0603_1608Metric_Pad1.08x0.95mm_HandSolder | YAGEO | CC0603MRX7R9BB104
C44 | 100nF | Capacitor_SMD:C_0603_1608Metric_Pad1.08x0.95mm_HandSolder | YAGEO | CC0603MRX7R9BB104
C45 | 18pF | Capacitor_SMD:C_0603_1608Metric_Pad1.08x0.95mm_HandSolder | Murata Electronics | GRM1885C2A180JA01D
C46 | 18pF | Capacitor_SMD:C_0603_1608Metric_Pad1.08x0.95mm_HandSolder | Murata Electronics | GRM1885C2A180JA01D
C47 | 100nF | Capacitor_SMD:C_0603_1608Metric_Pad1.08x0.95mm_HandSolder | YAGEO | CC0603MRX7R9BB104
C48 | 220nF | Capacitor_SMD:C_0603_1608Metric_Pad1.08x0.95mm_HandSolder | KEMET | C0603C224K3RACTU
C49 | 220nF | Capacitor_SMD:C_0603_1608Metric_Pad1.08x0.95mm_HandSolder | KEMET | C0603C224K3RACTU
C50 | 0.1uF | Capacitor_SMD:C_0603_1608Metric_Pad1.08x0.95mm_HandSolder | YAGEO | CC0603MRY5V9BB104
C51 | 1uF | Capacitor_SMD:C_0603_1608Metric_Pad1.08x0.95mm_HandSolder | YAGEO | CC0603KRX7R7BB105
C52 | 1uF | Capacitor_SMD:C_0603_1608Metric_Pad1.08x0.95mm_HandSolder | YAGEO | CC0603KRX7R7BB105
C53 | 1uF | Capacitor_SMD:C_0603_1608Metric_Pad1.08x0.95mm_HandSolder | YAGEO | CC0603KRX7R7BB105
C54 | 1uF | Capacitor_SMD:C_0603_1608Metric_Pad1.08x0.95mm_HandSolder | YAGEO | CC0603KRX7R7BB105
C55 | 1uF | Capacitor_SMD:C_0603_1608Metric_Pad1.08x0.95mm_HandSolder | YAGEO | CC0603KRX7R7BB105
C56 | 1uF | Capacitor_SMD:C_0603_1608Metric_Pad1.08x0.95mm_HandSolder | YAGEO | CC0603KRX7R7BB105
C57 | 1uF | Capacitor_SMD:C_0603_1608Metric_Pad1.08x0.95mm_HandSolder | YAGEO | CC0603KRX7R7BB105
C58 | 1uF | Capacitor_SMD:C_0603_1608Metric_Pad1.08x0.95mm_HandSolder | YAGEO | CC0603KRX7R7BB105
C59 | 10nF | Capacitor_SMD:C_0603_1608Metric_Pad1.08x0.95mm_HandSolder | Murata Electronics | GCM188R71H103KA37J
C60 | 2.2nF | Capacitor_SMD:C_0603_1608Metric_Pad1.08x0.95mm_HandSolder | KEMET | C0603X222F4HACTU
C61 | 2.2nF | Capacitor_SMD:C_0603_1608Metric_Pad1.08x0.95mm_HandSolder | KEMET | C0603X222F4HACTU
C62 | 2.2nF | Capacitor_SMD:C_0603_1608Metric_Pad1.08x0.95mm_HandSolder | KEMET | C0603X222F4HACTU
C63 | 2.2nF | Capacitor_SMD:C_0603_1608Metric_Pad1.08x0.95mm_HandSolder | KEMET | C0603X222F4HACTU
C64 | 2.2nF | Capacitor_SMD:C_0603_1608Metric_Pad1.08x0.95mm_HandSolder | KEMET | C0603X222F4HACTU
C65 | 2.2nF | Capacitor_SMD:C_0603_1608Metric_Pad1.08x0.95mm_HandSolder | KEMET | C0603X222F4HACTU
C66 | 2.2nF | Capacitor_SMD:C_0603_1608Metric_Pad1.08x0.95mm_HandSolder | KEMET | C0603X222F4HACTU
C67 | 2.2nF | Capacitor_SMD:C_0603_1608Metric_Pad1.08x0.95mm_HandSolder | KEMET | C0603X222F4HACTU
C68 | 2.2nF | Capacitor_SMD:C_0603_1608Metric_Pad1.08x0.95mm_HandSolder | KEMET | C0603X222F4HACTU
C69 | 2.2nF | Capacitor_SMD:C_0603_1608Metric_Pad1.08x0.95mm_HandSolder | KEMET | C0603X222F4HACTU
C70 | 2.2nF | Capacitor_SMD:C_0603_1608Metric_Pad1.08x0.95mm_HandSolder | KEMET | C0603X222F4HACTU
C71 | 2.2nF | Capacitor_SMD:C_0603_1608Metric_Pad1.08x0.95mm_HandSolder | KEMET | C0603X222F4HACTU
C72 | 2.2nF | Capacitor_SMD:C_0603_1608Metric_Pad1.08x0.95mm_HandSolder | KEMET | C0603X222F4HACTU
C73 | 100nF | Capacitor_SMD:C_0603_1608Metric_Pad1.08x0.95mm_HandSolder | YAGEO | CC0603MRX7R9BB104
C74 | 100nF | Capacitor_SMD:C_0603_1608Metric_Pad1.08x0.95mm_HandSolder | YAGEO | CC0603MRX7R9BB104
D1 | LED | LED_SMD:LED_0603_1608Metric_Pad1.05x0.95mm_HandSolder | Lite-On Inc. | LTST-C190KRKT
D2 | LED | LED_SMD:LED_0603_1608Metric_Pad1.05x0.95mm_HandSolder | Lite-On Inc. | LTST-C190KRKT
D3 | LED | LED_SMD:LED_0603_1608Metric_Pad1.05x0.95mm_HandSolder | Lite-On Inc. | LTST-C190KRKT
D4 | LED | LED_SMD:LED_0603_1608Metric_Pad1.05x0.95mm_HandSolder
D5 | D_Schottky | Diode_SMD:D_0603_1608Metric_Pad1.05x0.95mm_HandSolder | . | .
D6 | D_Schottky | Diode_SMD:D_0603_1608Metric_Pad1.05x0.95mm_HandSolder | . | .
J1 | Conn_01x02 | Connector_JST:JST_PH_B2B-PH-K_1x02_P2.00mm_Vertical | JST Sales America Inc. | B2B-XH-A
J2 | USB_C_Receptacle_USB2.0_16P | Connector_USB:USB_C_Receptacle_GCT_USB4105-xx-A_16P_TopMnt_Horizontal | GCT | USB4105-GF-A
J3 | Screw_Terminal_01x02 | TerminalBlock_Phoenix:TerminalBlock_Phoenix_MPT-0,5-2-2.54_1x02_P2.54mm_Horizontal | . | .
J4 | Conn_01x05 | Connector_PinSocket_2.54mm:PinSocket_1x05_P2.54mm_Vertical | . | .
J5 | Conn_01x02 | Connector_PinHeader_2.54mm:PinHeader_1x02_P2.54mm_Vertical | . | .
J6 | USB_C_Receptacle_USB2.0_16P | Connector_USB:USB_C_Receptacle_GCT_USB4105-xx-A_16P_TopMnt_Horizontal | GCT | USB4105-GF-A
J7 | Conn_01x32 | Connector_PinHeader_1.27mm:PinHeader_1x32_P1.27mm_Vertical | . | .
J8 | Conn_01x32 | Connector_PinHeader_1.27mm:PinHeader_1x32_P1.27mm_Vertical | . | .
L1 | 2.2uH | Inductor_SMD:L_0603_1608Metric_Pad1.05x0.95mm_HandSolder | Abracon LLC | ASMPH-0603-2R2M-T
R1 | 10K | Resistor_SMD:R_0603_1608Metric_Pad0.98x0.95mm_HandSolder | YAGEO | RC0603FR-1010KL
R2 | 10K | Resistor_SMD:R_0603_1608Metric_Pad0.98x0.95mm_HandSolder | YAGEO | RC0603FR-1010KL
R3 | 100E | Resistor_SMD:R_0603_1608Metric_Pad0.98x0.95mm_HandSolder | YAGEO | RC0603FR-07100RL
R4 | 10K | Resistor_SMD:R_0603_1608Metric_Pad0.98x0.95mm_HandSolder | YAGEO | RC0603FR-1010KL
R5 | 1K | Resistor_SMD:R_0603_1608Metric_Pad0.98x0.95mm_HandSolder | YAGEO | RT0603BRD131KL
R6 | 1K | Resistor_SMD:R_0603_1608Metric_Pad0.98x0.95mm_HandSolder | YAGEO | RT0603BRD131KL
R7 | 1.13K | Resistor_SMD:R_0603_1608Metric_Pad0.98x0.95mm_HandSolder | YAGEO | RT0603FRE071K13L
R8 | 1.18K | Resistor_SMD:R_0603_1608Metric_Pad0.98x0.95mm_HandSolder | YAGEO | RC0603FR-071K18L
R9 | 0.01 | Resistor_SMD:R_0603_1608Metric_Pad0.98x0.95mm_HandSolder | YAGEO | PF0603FRE7T0R01Z
R10 | 4.7K | Resistor_SMD:R_0603_1608Metric_Pad0.98x0.95mm_HandSolder | YAGEO | RC0603JR-074K7L
R11 | 10K | Resistor_SMD:R_0603_1608Metric_Pad0.98x0.95mm_HandSolder | YAGEO | RC0603FR-1010KL
R12 | 4.7K | Resistor_SMD:R_0603_1608Metric_Pad0.98x0.95mm_HandSolder | YAGEO | RC0603JR-074K7L
R13 | 4.7K | Resistor_SMD:R_0603_1608Metric_Pad0.98x0.95mm_HandSolder | YAGEO | RC0603JR-074K7L
R14 | 820E | Resistor_SMD:R_0603_1608Metric_Pad0.98x0.95mm_HandSolder | YAGEO | AC0603JR-07820RL
R15 | 10K | Resistor_SMD:R_0603_1608Metric_Pad0.98x0.95mm_HandSolder | YAGEO | RC0603FR-1010KL
R16 | 22E | Resistor_SMD:R_0603_1608Metric_Pad0.98x0.95mm_HandSolder | YAGEO | RC0603JR-0722RL
R17 | 22E | Resistor_SMD:R_0603_1608Metric_Pad0.98x0.95mm_HandSolder | YAGEO | RC0603JR-0722RL
R18 | 10K | Resistor_SMD:R_0603_1608Metric_Pad0.98x0.95mm_HandSolder | YAGEO | RC0603FR-1010KL
R19 | 10K | Resistor_SMD:R_0603_1608Metric_Pad0.98x0.95mm_HandSolder | YAGEO | RC0603FR-1010KL
R20 | 5.1K | Resistor_SMD:R_0603_1608Metric_Pad0.98x0.95mm_HandSolder | YAGEO | RC0603JR-075K1L
R21 | 5.1K | Resistor_SMD:R_0603_1608Metric_Pad0.98x0.95mm_HandSolder | YAGEO | RC0603JR-075K1L
R22 | 10K | Resistor_SMD:R_0603_1608Metric_Pad0.98x0.95mm_HandSolder | YAGEO | RC0603FR-1010KL
R23 | 10K | Resistor_SMD:R_0603_1608Metric_Pad0.98x0.95mm_HandSolder | YAGEO | RC0603FR-1010KL
R24 | 10K | Resistor_SMD:R_0603_1608Metric_Pad0.98x0.95mm_HandSolder | YAGEO | RC0603FR-1010KL
R25 | 10K | Resistor_SMD:R_0603_1608Metric_Pad0.98x0.95mm_HandSolder | YAGEO | RC0603FR-1010KL
R26 | 10K | Resistor_SMD:R_0603_1608Metric_Pad0.98x0.95mm_HandSolder | YAGEO | RC0603FR-1010KL
R27 | 10K | Resistor_SMD:R_0603_1608Metric_Pad0.98x0.95mm_HandSolder | YAGEO | RC0603FR-1010KL
R28 | 10K | Resistor_SMD:R_0603_1608Metric_Pad0.98x0.95mm_HandSolder | YAGEO | RC0603FR-1010KL
R29 | 10K | Resistor_SMD:R_0603_1608Metric_Pad0.98x0.95mm_HandSolder | YAGEO | RC0603FR-1010KL
R30 | 10K | Resistor_SMD:R_0603_1608Metric_Pad0.98x0.95mm_HandSolder | YAGEO | RC0603FR-1010KL
R31 | 10K | Resistor_SMD:R_0603_1608Metric_Pad0.98x0.95mm_HandSolder | YAGEO | RC0603FR-1010KL
R32 | 10K | Resistor_SMD:R_0603_1608Metric_Pad0.98x0.95mm_HandSolder | YAGEO | RC0603FR-1010KL
R33 | 10K | Resistor_SMD:R_0603_1608Metric_Pad0.98x0.95mm_HandSolder | YAGEO | RC0603FR-1010KL
R34 | 10K | Resistor_SMD:R_0603_1608Metric_Pad0.98x0.95mm_HandSolder | YAGEO | RC0603FR-1010KL
R35 | 10K | Resistor_SMD:R_0603_1608Metric_Pad0.98x0.95mm_HandSolder | YAGEO | RC0603FR-1010KL
R36 | 10K | Resistor_SMD:R_0603_1608Metric_Pad0.98x0.95mm_HandSolder | YAGEO | RC0603FR-1010KL
R37 | 10K | Resistor_SMD:R_0603_1608Metric_Pad0.98x0.95mm_HandSolder | YAGEO | RC0603FR-1010KL
R38 | 10K | Resistor_SMD:R_0603_1608Metric_Pad0.98x0.95mm_HandSolder | YAGEO | RC0603FR-1010KL
R39 | 10K | Resistor_SMD:R_0603_1608Metric_Pad0.98x0.95mm_HandSolder | YAGEO | RC0603FR-1010KL
R40 | 10K | Resistor_SMD:R_0603_1608Metric_Pad0.98x0.95mm_HandSolder | YAGEO | RC0603FR-1010KL
R41 | 10K | Resistor_SMD:R_0603_1608Metric_Pad0.98x0.95mm_HandSolder | YAGEO | RC0603FR-1010KL
R42 | 10K | Resistor_SMD:R_0603_1608Metric_Pad0.98x0.95mm_HandSolder | YAGEO | RC0603FR-1010KL
R43 | 10K | Resistor_SMD:R_0603_1608Metric_Pad0.98x0.95mm_HandSolder | YAGEO | RC0603FR-1010KL
R44 | 10K | Resistor_SMD:R_0603_1608Metric_Pad0.98x0.95mm_HandSolder | YAGEO | RC0603FR-1010KL
R45 | 10K | Resistor_SMD:R_0603_1608Metric_Pad0.98x0.95mm_HandSolder | YAGEO | RC0603FR-1010KL
R52 | 5.1K | Resistor_SMD:R_0603_1608Metric_Pad0.98x0.95mm_HandSolder | YAGEO | RC0603JR-075K1L
R53 | 5.1K | Resistor_SMD:R_0603_1608Metric_Pad0.98x0.95mm_HandSolder | YAGEO | RC0603JR-075K1L
R79 | 27E | Resistor_SMD:R_0603_1608Metric_Pad0.98x0.95mm_HandSolder | YAGEO | RT0603BRB0727RL
R80 | 27E | Resistor_SMD:R_0603_1608Metric_Pad0.98x0.95mm_HandSolder | YAGEO | RT0603BRB0727RL
R81 | 1K | Resistor_SMD:R_0603_1608Metric_Pad0.98x0.95mm_HandSolder | YAGEO | RT0603BRD131KL
R82 | 10K | Resistor_SMD:R_0603_1608Metric_Pad0.98x0.95mm_HandSolder | YAGEO | RC0603FR-1010KL
SW1 | KSS221GLFS | Snapeda:SW_KSS221GLFS_CNK | C&K | KSS221G LFS
SW2 | KSS221GLFS | Snapeda:SW_KSS221GLFS_CNK | C&K | KSS221G LFS
SW3 | KSS221GLFS | Snapeda:SW_KSS221GLFS_CNK | C&K | KSS221G LFS
SW4 | KSS221GLFS | Snapeda:SW_KSS221GLFS_CNK | C&K | KSS221G LFS
U1 | SMD_Series | Snapeda:SMD_Series | Winsen | SMD1001
U2 | SMD_Series | Snapeda:SMD_Series | Winsen | SMD1001
U3 | TPS63001 | Snapeda:Texas_DRC0010J_ThermalVias | Texas Instruments | TPS63001DRCR
U4 | BQ24075RGTR | Snapeda:RGT16_1P7X1P7 | Texas Instruments | BQ24075RGTR
U5 | BME680 | Package_LGA:Bosch_LGA-8_3x3mm_P0.8mm_ClockwisePinNumbering | SparkFun | SEN-16466
U6 | BQ27441DRZR-G1A | Snapeda:DRZ0012A | Texas Instruments | BQ27441DRZR-G1A
U7 | SMD_Series | Snapeda:SMD_Series | Winsen | SMD1001
U8 | SMD_Series | Snapeda:SMD_Series | Winsen | SMD1001
U9 | SMD_Series | Snapeda:SMD_Series | Winsen | SMD1001
U10 | GM_Series | Snapeda:GM102B | Winsen | GM-302B
U11 | SMD_Series | Snapeda:SMD_Series | Winsen | SMD1001
U12 | SMD_Series | Snapeda:SMD_Series | Winsen | SMD1001
U13 | TLV9152 | Snapeda:DDF0008A-IPC_A | Texas Instruments | TLV9152IDDFR
U14 | GM_Series | Snapeda:GM102B | Winsen | GM-302B
U15 | GM_Series | Snapeda:GM102B | Winsen | GM-512B
U16 | GM_Series | Snapeda:GM202_502B | Winsen | GM-202B
U17 | GM_Series | Snapeda:GM102B | Winsen | GM-2021B
U18 | GM_Series | Snapeda:GM102B | Winsen | GM-102B
U19 | TLV9152 | Snapeda:DDF0008A-IPC_A | Texas Instruments | TLV9152IDDFR
U20 | GM_Series | Snapeda:GM202_502B | Winsen | GM-302B
U21 | TLV9152 | Snapeda:DDF0008A-IPC_A | Texas Instruments | TLV9152IDDFR
U22 | TLV9152 | Snapeda:DDF0008A-IPC_A | Texas Instruments | TLV9152IDDFR
U23 | ADS131M08IPBSR | Snapeda:PBS0032A_L | Texas Instruments | ADS131M08IPBSR
U24 | ADS131M08IPBSR | Snapeda:PBS0032A_L | Texas Instruments | ADS131M08IPBSR
U25 | TLV9152 | Snapeda:DDF0008A-IPC_A | Texas Instruments | TLV9152IDDFR
U26 | MPM3805GQB-25-Z | Snapeda:QFN2p5x3p0x0p9_MNP | Monolithic Power Systems Inc. | MPM3805GQB-25-Z
U27 | MPM3805GQB-18-P | Snapeda:QFN2p5x3p0x0p9_MNP | Monolithic Power Systems Inc. | MPM3805GQB-18-P
U28 | ESP32-S3-WROOM-1-N16 | Snapeda:ESP32-S3-WROOM-1 | Espressif Systems | ESP32-S3-WROOM-1-N16
U29 | TLV9152 | Snapeda:DDF0008A-IPC_A | Texas Instruments | TLV9152IDDFR
U30 | TLV9152 | Snapeda:DDF0008A-IPC_A | Texas Instruments | TLV9152IDDFR
U31 | TLV9152 | Snapeda:DDF0008A-IPC_A | Texas Instruments | TLV9152IDDFR
U32 | TLV9152 | Snapeda:DDF0008A-IPC_A | Texas Instruments | TLV9152IDDFR
U33 | TLV9152 | Snapeda:DDF0008A-IPC_A | Texas Instruments | TLV9152IDDFR
U34 | TLV9152 | Snapeda:DDF0008A-IPC_A | Texas Instruments | TLV9152IDDFR
U35 | TLV9152 | Snapeda:DDF0008A-IPC_A | Texas Instruments | TLV9152IDDFR
U36 | TLV9152 | Snapeda:DDF0008A-IPC_A | Texas Instruments | TLV9152IDDFR
U37 | TLV9152 | Snapeda:DDF0008A-IPC_A | Texas Instruments | TLV9152IDDFR
U38 | SC091413 | Snapeda:QFN56_7X7_RPI-L | Raspberry Pi | SC0914(13)
U39 | TBD62083AFNG_EL | Snapeda:SSOP18-P-225-0p65_TOS-L | Toshiba Semiconductor and Storage | TBD62083AFNG,EL
U40 | TBD62083AFNG_EL | Snapeda:SSOP18-P-225-0p65_TOS-L | Toshiba Semiconductor and Storage | TBD62083AFNG,EL
U41 | W25Q32JVSS | Package_SO:SOIC-8_5.3x5.3mm_P1.27mm | Winbond Electronics | W25Q32JVSSIQ
Y1 | ABM8G-12.000MHZ-18-D2Y-T | Snapeda:CRYSTAL_ABM8G_ABR-L | Abracon LLC | ABM8G-12.000MHZ-18-D2Y-T
Y2 | SG-210STF | Oscillator:Oscillator_SMD_SeikoEpson_SG210-4Pin_2.5x2.0mm | EPSON | SG-210STF 8.1920ML
Y3 | SG-210STF | Oscillator:Oscillator_SMD_SeikoEpson_SG210-4Pin_2.5x2.0mm | EPSON | SG-210STF 8.1920ML

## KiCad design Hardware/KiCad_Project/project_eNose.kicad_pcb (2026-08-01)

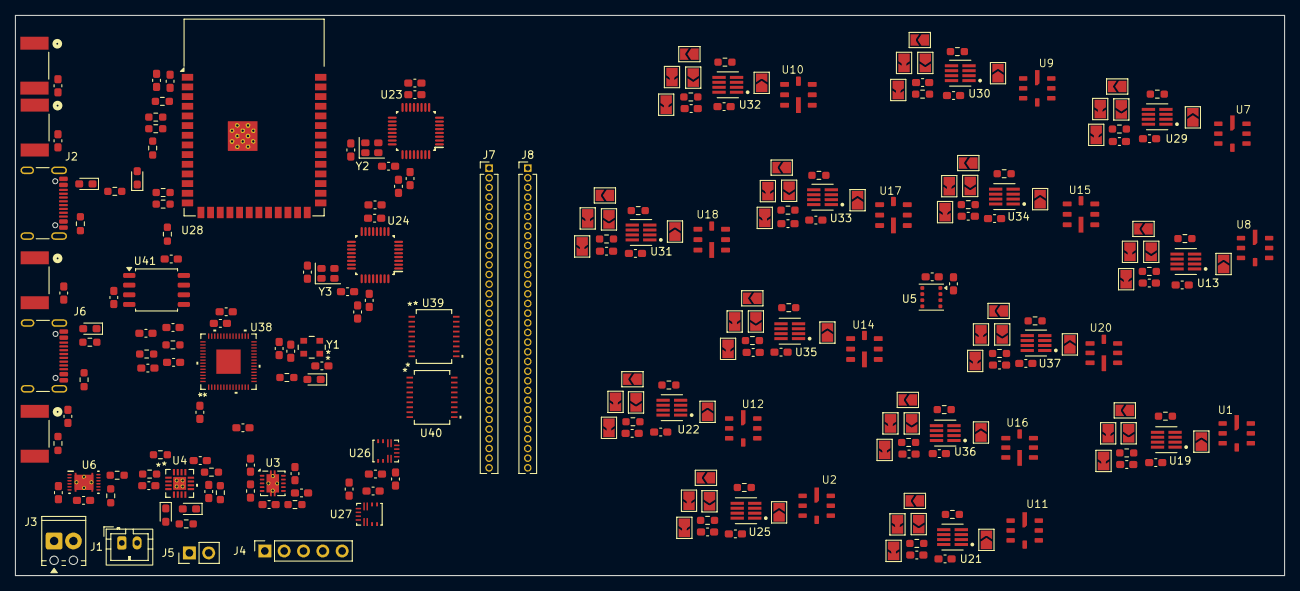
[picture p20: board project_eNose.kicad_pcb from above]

Board: 2 copper layers, 166.7 x 73.6 mm, 262 parts (0 on the bottom side), 198 nets, no tracks yet.

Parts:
C1, C2, C4, C5, C9, C32, C41, C50: 0.1uF; C_0603_1608Metric_Pad1.08x0.95mm_HandSolder
C3, C60, C61, C62, C63, C64, C65, C66, C67, C68, C69, C70, C71, C72: 2.2nF; C_0603_1608Metric_Pad1.08x0.95mm_HandSolder
C6, C8, C10, C11, C12, C16, C17, C18, C19, C25, C26, C27, C31, C59: 10nF; C_0603_1608Metric_Pad1.08x0.95mm_HandSolder
C7, C13, C14, C20, C21, C22, C24: 10uF; C_0603_1608Metric_Pad1.08x0.95mm_HandSolder
C15, C23: 4.7uF; C_0603_1608Metric_Pad1.08x0.95mm_HandSolder
C28, C30, C38, C51, C52, C53, C54, C55, C56, C57, C58: 1uF; C_0603_1608Metric_Pad1.08x0.95mm_HandSolder
C29: 0.47uF; C_0603_1608Metric_Pad1.08x0.95mm_HandSolder
C33, C34, C35, C36, C37, C39, C40, C43, C44, C47, C73, C74: 100nF; C_0603_1608Metric_Pad1.08x0.95mm_HandSolder
C42: 22uF; C_0603_1608Metric_Pad1.08x0.95mm_HandSolder
C45, C46: 18pF; C_0603_1608Metric_Pad1.08x0.95mm_HandSolder
C48, C49: 220nF; C_0603_1608Metric_Pad1.08x0.95mm_HandSolder
D1, D2, D3, D4: LED; LED_0603_1608Metric_Pad1.05x0.95mm_HandSolder
D5, D6: D_Schottky; D_0603_1608Metric_Pad1.05x0.95mm_HandSolder
H1, H2, H3, H4: MountingHole; MountingHole_2mm
J1: Conn_01x02; JST_PH_B2B-PH-K_1x02_P2.00mm_Vertical
J2, J6: USB_C_Receptacle_USB2.0_16P; USB_C_Receptacle_GCT_USB4105-xx-A_16P_TopMnt_Horizontal
J3: Screw_Terminal_01x02; TerminalBlock_Phoenix_MPT-0,5-2-2.54_1x02_P2.54mm_Horizontal
J4: Conn_01x05; PinSocket_1x05_P2.54mm_Vertical
J5: Conn_01x02; PinHeader_1x02_P2.54mm_Vertical
J7, J8: Conn_01x32; PinHeader_1x32_P1.27mm_Vertical
JP1, JP2, JP45, JP46, JP47, JP48, JP49, JP50, JP51, JP52, JP53, JP54, JP55, JP56, JP57, JP58, JP59, JP60, JP61, JP62, JP63, JP64, JP65, JP66, JP67, JP68, JP69, JP70: SolderJumper_2_Bridged; SolderJumper-2_P1.3mm_Bridged_TrianglePad1.0x1.5mm_FIXED
JP3, JP4, JP5, JP6, JP7, JP8, JP9, JP10, JP11, JP12, JP13, JP14, JP15, JP16, JP17, JP18, JP19, JP20, JP21, JP22, JP23, JP24, JP25, JP26, JP27, JP28, JP29, JP30, JP31, JP32, JP33, JP34, JP35, JP36, JP37, JP38, JP39, JP40, JP41, JP42, JP43, JP44: SolderJumper_2_Open; SolderJumper-2_P1.3mm_Open_TrianglePad1.0x1.5mm
L1: 2.2uH; L_0603_1608Metric_Pad1.05x0.95mm_HandSolder
R1, R2, R4, R11, R15, R18, R19, R22, R23, R24, R25, R26, R27, R28, R29, R30, R31, R32, R33, R34, R35, R36, R37, R38, R39, R40, R41, R42, R43, R44, R45, R82: 10K; R_0603_1608Metric_Pad0.98x0.95mm_HandSolder
R3: 100E; R_0603_1608Metric_Pad0.98x0.95mm_HandSolder
R5, R6, R81: 1K; R_0603_1608Metric_Pad0.98x0.95mm_HandSolder
R7: 1.13K; R_0603_1608Metric_Pad0.98x0.95mm_HandSolder
R8: 1.18K; R_0603_1608Metric_Pad0.98x0.95mm_HandSolder
R9: 0.01; R_0603_1608Metric_Pad0.98x0.95mm_HandSolder
R10, R12, R13: 4.7K; R_0603_1608Metric_Pad0.98x0.95mm_HandSolder
R14: 820E; R_0603_1608Metric_Pad0.98x0.95mm_HandSolder
R16, R17: 22E; R_0603_1608Metric_Pad0.98x0.95mm_HandSolder
R20, R21, R52, R53: 5.1K; R_0603_1608Metric_Pad0.98x0.95mm_HandSolder
R79, R80: 27E; R_0603_1608Metric_Pad0.98x0.95mm_HandSolder
SW1, SW2, SW3, SW4: KSS221GLFS; SW_KSS221GLFS_CNK
U1, U2, U7, U8, U9, U11, U12: SMD_Series
U3: TPS63001; Texas_DRC0010J_ThermalVias
U4: BQ24075RGTR; RGT16_1P7X1P7
U5: BME680; Bosch_LGA-8_3x3mm_P0.8mm_ClockwisePinNumbering
U6: BQ27441DRZR-G1A; DRZ0012A
U10, U14, U15, U17, U18: GM_Series; GM102B
U13, U19, U21, U22, U25, U29, U30, U31, U32, U33, U34, U35, U36, U37: TLV9152; DDF0008A-IPC_A
U16, U20: GM_Series; GM202_502B
U23, U24: ADS131M08IPBSR; PBS0032A_L
U26: MPM3805GQB-25-Z; QFN2p5x3p0x0p9_MNP
U27: MPM3805GQB-18-P; QFN2p5x3p0x0p9_MNP
U28: ESP32-S3-WROOM-1-N16; ESP32-S3-WROOM-1
U38: SC091413; QFN56_7X7_RPI-L
U39, U40: TBD62083AFNG_EL; SSOP18-P-225-0p65_TOS-L
U41: W25Q32JVSS; SOIC-8_5.3x5.3mm_P1.27mm
Y1: ABM8G-12.000MHZ-18-D2Y-T; CRYSTAL_ABM8G_ABR-L
Y2, Y3: SG-210STF; Oscillator_SMD_SeikoEpson_SG210-4Pin_2.5x2.0mm

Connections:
1p8V: C22.1, C34.2, J7.31, J8.31, U1.1 (VH+), U2.1 (VH+), U7.1 (VH+), U8.1 (VH+), U9.1 (VH+), U10.1 (VH+), U11.1 (VH+), U12.1 (VH+), U18.1 (VH+), U27.5 (OUT), U27.6 (OUT), U27.12 (OUT_S), U41.8 (VCC)
2p5V: C20.1, J7.30, J8.30, U14.1 (VH+), U15.1 (VH+), U16.1 (VH+), U17.1 (VH+), U20.1 (VH+), U26.5 (OUT), U26.6 (OUT), U26.12 (OUT_S)
3p3V: C4.1, C5.1, C6.2, C8.2, C10.2, C11.2, C12.2, C13.1, C14.1, C16.2, C17.2, C18.2, C19.2, C25.2, C26.2, C27.2, C31.2, C33.2, C35.2, C36.2, C37.2, C38.2, C39.2, C40.2, C41.2, C42.2, C43.2, C44.2, C47.2, C51.2, C52.2, C53.2, C54.2, C55.2, C56.2, C57.2, C58.2, C59.2, C73.2, C74.1, J4.1, J7.29, J8.29, R10.1, R12.1, R13.1, R15.1, R82.2, U1.2 (VCC), U2.2 (VCC), U3.1 (VOUT), U3.10 (FB), U5.2 (CSB), U5.6 (VDDIO), U5.8 (VDD), U7.2 (VCC), U8.2 (VCC), U9.2 (VCC), U10.7 (VCC), U11.2 (VCC), U12.2 (VCC), U13.8 (V+), U14.7 (VCC), U15.7 (VCC), U16.7 (VCC), U17.7 (VCC), U18.7 (VCC), U19.8 (V+), U20.7 (VCC), U21.8 (V+), U22.8 (V+), U23.14 (REFIN), U23.15 (AVDD), U23.26 (IOVDD), U23.27 (AVDD), U24.14 (REFIN), U24.15 (AVDD), U24.26 (IOVDD), U24.27 (AVDD), U25.8 (V+), U28.2 (3V3), U29.8 (V+), U30.8 (V+), U31.8 (V+), U32.8 (V+), U33.8 (V+), U34.8 (V+), U35.8 (V+), U36.8 (V+), U37.8 (V+), U38.1 (IOVDD), U38.10 (IOVDD), U38.22 (IOVDD), U38.33 (IOVDD), U38.42 (IOVDD), U38.43 (ADC_AVDD), U38.44 (VREG_VIN), U38.48 (USB_VDD), U38.49 (IOVDD), Y2.4 (Vcc), Y3.4 (Vcc)
/Acetone/OUT1: JP16.1 (A), JP17.1 (A), U29.1 (1OUT), U29.2 (1IN-), U29.5 (2IN+)
/Alcohol/OUT1: JP34.1 (A), JP35.1 (A), U35.1 (1OUT), U35.2 (1IN-), U35.5 (2IN+)
/BME680 (Temp., Air, Humidity)/I2C.SCL: R13.2, U5.4 (SCK), U6.2 (SCL), U28.6 (IO6)
/BME680 (Temp., Air, Humidity)/I2C.SDA: R12.2, U5.3 (SDI), U6.1 (SDA), U28.5 (IO5)
/Breath Smell/OUT1: JP31.1 (A), JP32.1 (A), U34.1 (1OUT), U34.2 (1IN-), U34.5 (2IN+)
/CH4/OUT1: JP10.1 (A), JP11.1 (A), U22.1 (1OUT), U22.2 (1IN-), U22.5 (2IN+)
/Charger-Regulator/BatP: C15.1, C29.2, C30.1, J1.1, J3.1, J5.1, R9.1, U4.2 (BAT), U4.3 (BAT), U6.5 (VDD), U6.6 (BAT), U6.8 (SRP)
/Charger-Regulator/VIN: C28.1, D5.1 (K), D6.1 (K), U4.13 (IN)
/Charger-Regulator/VSYS: C7.1, C21.1, C23.1, C24.1, R3.1, R6.2, R9.2, U3.5 (VIN), U4.5 (EN2), U4.10 (OUT), U4.11 (OUT), U6.7 (SRN), U26.7 (VIN), U26.9 (EN), U27.7 (VIN), U27.9 (EN)
/H2/OUT1: JP28.1 (A), JP29.1 (A), U33.1 (1OUT), U33.2 (1IN-), U33.5 (2IN+)
/H2S & Benzene/OUT1: JP25.1 (A), JP26.1 (A), U32.1 (1OUT), U32.2 (1IN-), U32.5 (2IN+)
/H2S/OUT1: JP7.1 (A), JP8.1 (A), U25.1 (1OUT), U25.2 (1IN-), U25.5 (2IN+)
/HCHO/OUT1: JP3.1 (A), JP43.1 (A), U13.1 (1OUT), U13.2 (1IN-), U13.5 (2IN+)
/NH3/OUT1: JP4.1 (A), JP5.1 (A), U19.1 (1OUT), U19.2 (1IN-), U19.5 (2IN+)
/NO2/OUT1: JP22.1 (A), JP23.1 (A), U31.1 (1OUT), U31.2 (1IN-), U31.5 (2IN+)
/Perforated-Connectors/A0: C3.2, J7.1, J8.1, R23.2, U13.7 (2OUT), U23.29 (AIN0P)
/Perforated-Connectors/A1: C60.2, J7.2, J8.2, R11.2, U19.7 (2OUT), U23.32 (AIN1P)
/Perforated-Connectors/A2: C61.2, J7.3, J8.3, R19.2, U23.1 (AIN2P), U25.7 (2OUT)
/Perforated-Connectors/A3: C62.2, J7.4, J8.4, R25.2, U22.7 (2OUT), U23.4 (AIN3P)
/Perforated-Connectors/A4: C63.2, J7.5, J8.5, R27.2, U21.7 (2OUT), U23.5 (AIN4P)
/Perforated-Connectors/A5: C64.2, J7.6, J8.6, R29.2, U23.8 (AIN5P), U29.7 (2OUT)
/Perforated-Connectors/A6: C65.2, J7.7, J8.7, R31.2, U23.9 (AIN6P), U30.7 (2OUT)
/Perforated-Connectors/A7: C66.2, J7.8, J8.8, R33.2, U24.29 (AIN0P), U31.7 (2OUT)
/Perforated-Connectors/A8: C67.2, J7.9, J8.9, R35.2, U24.32 (AIN1P), U32.7 (2OUT)
/Perforated-Connectors/A9: C68.2, J7.10, J8.10, R37.2, U24.1 (AIN2P), U33.7 (2OUT)
/Perforated-Connectors/A10: C69.2, J7.11, J8.11, R39.2, U24.4 (AIN3P), U34.7 (2OUT)
/Perforated-Connectors/A11: C70.2, J7.12, J8.12, R41.2, U24.5 (AIN4P), U35.7 (2OUT)
/Perforated-Connectors/A12: C71.2, J7.13, J8.13, R43.2, U24.8 (AIN5P), U36.7 (2OUT)
/Perforated-Connectors/A13: C72.2, J7.14, J8.14, R45.2, U24.9 (AIN6P), U37.7 (2OUT)
/Perforated-Connectors/HOT0: J7.15, J8.15, U8.7 (HOT), U39.18 (O1)
/Perforated-Connectors/HOT1: J7.16, J8.16, U1.7 (HOT), U39.17 (O2)
/Perforated-Connectors/HOT2: J7.17, J8.17, U2.7 (HOT), U39.16 (O3)
/Perforated-Connectors/HOT3: J7.18, J8.18, U12.7 (HOT), U39.15 (O4)
/Perforated-Connectors/HOT4: J7.19, J8.19, U11.7 (HOT), U39.14 (O5)
/Perforated-Connectors/HOT5: J7.20, J8.20, U7.7 (HOT), U39.13 (O6)
/Perforated-Connectors/HOT6: J7.21, J8.21, U9.7 (HOT), U39.12 (O7)
/Perforated-Connectors/HOT7: J7.22, J8.22, U18.3 (HOT), U40.18 (O1)
/Perforated-Connectors/HOT8: J7.23, J8.23, U10.3 (HOT), U40.17 (O2)
/Perforated-Connectors/HOT9: J7.24, J8.24, U17.3 (HOT), U40.16 (O3)
/Perforated-Connectors/HOT10: J7.25, J8.25, U15.3 (HOT), U40.15 (O4)
/Perforated-Connectors/HOT11: J7.26, J8.26, U14.3 (HOT), U40.14 (O5)
/Perforated-Connectors/HOT12: J7.27, J8.27, U16.3 (HOT), U40.13 (O6)
/Perforated-Connectors/HOT13: J7.28, J8.28, U20.3 (HOT), U40.12 (O7)
/Propane/OUT1: JP13.1 (A), JP14.1 (A), U21.1 (1OUT), U21.2 (1IN-), U21.5 (2IN+)
/RP2040/CLK: U38.52 (SQPI_SCLK), U41.6 (CLK)
/RP2040/CS: U38.56 (SQPI_SS_N), U41.1 (~CS)
/RP2040/DVDD: U38.23 (DVDD), U38.45 (VREG_VOUT), U38.50 (DVDD)
/RP2040/IO0: U38.53 (SQPI_SD0), U41.5 (DI/IO_{0})
/RP2040/IO1: U38.55 (SQPI_SD1), U41.2 (DO/IO_{1})
/RP2040/IO2: U38.54 (SQPI_SD2), U41.3 (~WP/IO_{2})
/RP2040/IO3: U38.51 (SQPI_SD3), U41.7 (~HOLD/~RESET/IO_{3})
/RP2040/PWM0: U38.2 (GPIO0), U39.1 (I1)
/RP2040/PWM1: U38.3 (GPIO1), U39.2 (I2)
/RP2040/PWM2: U38.4 (GPIO2), U39.3 (I3)
/RP2040/PWM3: U38.5 (GPIO3), U39.4 (I4)
/RP2040/PWM4: U38.6 (GPIO4), U39.5 (I5)
/RP2040/PWM5: U38.7 (GPIO5), U39.6 (I6)
/RP2040/PWM6: U38.8 (GPIO6), U39.7 (I7)
/RP2040/PWM7: U38.9 (GPIO7), U40.1 (I1)
/RP2040/PWM8: U38.11 (GPIO8), U40.2 (I2)
/RP2040/PWM9: U38.12 (GPIO9), U40.3 (I3)
/RP2040/PWM10: U38.13 (GPIO10), U40.4 (I4)
/RP2040/PWM11: U38.14 (GPIO11), U40.5 (I5)
/RP2040/PWM12: U38.15 (GPIO12), U40.6 (I6)
/RP2040/PWM13: U38.16 (GPIO13), U40.7 (I7)
/RP2040/RUN_RESET: C32.2, J4.5, R82.1, SW3.2, U38.26 (RUN)
/RP2040/SPI0: U28.39 (IO1), U38.32 (GPIO21)
/RP2040/SPI1: U28.38 (IO2), U38.31 (GPIO20)
/RP2040/SPI2: U28.10 (IO17), U38.30 (GPIO19)
/RP2040/SPI3: U28.11 (IO18), U38.29 (GPIO18)
/RP2040/SWD_IO: J4.3, U38.25 (SWDIO)
/RP2040/SW_CLK: J4.4, U38.24 (SWCLK)
/RP2040/UART.Rx: U28.37 (TXD0), U38.28 (GPIO17)
/RP2040/UART.Tx: U28.36 (RXD0), U38.27 (GPIO16)
/RP2040/USB1.Dm: J6.A7 (D-), J6.B7 (D-), R80.1
/RP2040/USB1.Dp: J6.A6 (D+), J6.B6 (D+), R79.2
/RP2040/XIN: C45.2, U38.20 (XIN), Y1.1
/RP2040/XOUT: C46.2, U38.21 (XOUT), Y1.3
/Smoke/OUT1: JP37.1 (A), JP38.1 (A), U36.1 (1OUT), U36.2 (1IN-), U36.5 (2IN+)
/TVOC/OUT1: JP19.1 (A), JP20.1 (A), U30.1 (1OUT), U30.2 (1IN-), U30.5 (2IN+)
/VOC/OUT1: JP40.1 (A), JP41.1 (A), U37.1 (1OUT), U37.2 (1IN-), U37.5 (2IN+)
/bat-conn-Monitor/GPOUT: R10.2, U6.12 (GPOUT), U28.15 (IO3)
/esp/Analog -> SPI/A_SPI0: U23.21 (DIN), U24.21 (DIN), U28.19 (IO11)
/esp/Analog -> SPI/A_SPI1: U23.20 (DOUT), U24.20 (DOUT), U28.21 (IO13)
/esp/Analog -> SPI/A_SPI2: U23.19 (SCLK), U24.19 (SCLK), U28.20 (IO12)
/esp/Analog -> SPI/A_SPI3: U23.18 (DRDY_N), U28.17 (IO9)
/esp/Analog -> SPI/A_SPI4: U23.17 (CS_N), U28.18 (IO10)
/esp/Analog -> SPI/A_SPI5: U23.16 (SYNC_RESET_N), U28.12 (IO8)
/esp/Analog -> SPI/A_SPI6: U24.18 (DRDY_N), U28.22 (IO14)
/esp/Analog -> SPI/A_SPI7: U24.17 (CS_N), U28.8 (IO15)
/esp/Analog -> SPI/A_SPI8: U24.16 (SYNC_RESET_N), U28.9 (IO16)
/esp/Analog -> SPI/CLKIN1: U23.23 (XTAL1_CLKIN), Y2.3 (OUT)
/esp/Analog -> SPI/CLKIN2: U24.23 (XTAL1_CLKIN), Y3.3 (OUT)
/esp/EN: C1.2, C2.2, R15.2, SW1.2, SW2.2, U28.3 (EN), U28.27 (IO0)
/esp/USB0.Dm: J2.A7 (D-), J2.B7 (D-), R17.1
/esp/USB0.Dp: J2.A6 (D+), J2.B6 (D+), R16.2
/esp/user_sw: C50.2, SW4.2, U28.4 (IO4)
GND: C1.1, C2.1, C4.2, C5.2, C6.1, C7.2, C8.1, C9.2, C10.1, C11.1, C12.1, C13.2, C14.2, C15.2, C16.1, C17.1, C18.1, C19.1, C20.2, C21.2, C22.2, C23.2, C24.2, C25.1, C26.1, C27.1, C28.2, C29.1, C30.2, C31.1, C32.1, C33.1, C34.1, C35.1, C36.1, C37.1, C38.1, C39.1, C40.1, C41.1, C42.1, C43.1, C44.1, C45.1, C46.1, C47.1, C48.1, C49.1, C50.1, C51.1, C52.1, C53.1, C54.1, C55.1, C56.1, C57.1, C58.1, C59.1, C73.1, C74.2, D1.1 (K), D4.1 (K), J1.2, J2.A1 (GND), J2.A12 (GND), J2.B1 (GND), J2.B12 (GND), J2.S1 (SHIELD), J3.2, J4.2, J5.2, J6.A1 (GND), J6.A12 (GND), J6.B1 (GND), J6.B12 (GND), J6.S1 (SHIELD), J7.32, J8.32, R1.1, R2.1, R4.1, R7.1, R8.1, R18.1, R20.2, R21.1, R22.1, R24.1, R26.1, R28.1, R30.1, R32.1, R34.1, R36.1, R38.1, R40.1, R42.1, R44.1, R52.2, R53.1, SW1.1, SW2.1, SW3.1, SW4.1, U3.3 (PGND), U3.9 (GND), U3.11 (PGND), U4.4 (*CE), U4.6 (EN1), U4.8 (VSS), U4.14 (TMR), U4.15 (SYSOFF), U4.17 (EPAD), U5.1 (GND), U5.5 (SDO), U5.7 (GND), U6.3 (VSS), U6.13 (PAD), U13.4 (V-), U19.4 (V-), U21.4 (V-), U22.4 (V-), U23.2 (AIN2N), U23.3 (AIN3N), U23.6 (AIN4N), U23.7 (AIN5N), U23.10 (AIN6N), U23.11 (AIN7N), U23.12 (AIN7P), U23.13 (AGND_REFGND), U23.25 (DGND), U23.28 (AGND), U23.30 (AIN0N), U23.31 (AIN1N), U24.2 (AIN2N), U24.3 (AIN3N), U24.6 (AIN4N), U24.7 (AIN5N), U24.10 (AIN6N), U24.11 (AIN7N), U24.12 (AIN7P), U24.13 (AGND_REFGND), U24.25 (DGND), U24.28 (AGND), U24.30 (AIN0N), U24.31 (AIN1N), U25.4 (V-), U26.1 (PGND), U26.2 (PGND), U26.11 (AGND), U27.1 (PGND), U27.2 (PGND), U27.11 (AGND), U28.1 (GND), U28.40 (GND), U28.41 (GND), U29.4 (V-), U30.4 (V-), U31.4 (V-), U32.4 (V-), U33.4 (V-), U34.4 (V-), U35.4 (V-), U36.4 (V-), U37.4 (V-), U38.19 (TESTEN), U38.35 (GPIO23), U38.57 (GND), U39.9 (GND), U40.9 (GND), U41.4 (GND), Y1.2, Y1.4, Y2.1 (~ST), Y2.2 (GND), Y3.1 (~ST), Y3.2 (GND)
unnamed: D1.2 (A), R14.2
unnamed: D2.2 (A), R5.2
unnamed: D2.1 (K), U4.7 (*PGOOD)
unnamed: D3.2 (A), R5.1, R6.1
unnamed: D3.1 (K), U4.9 (*CHG)
unnamed: D4.2 (A), R81.2
unnamed: D5.2 (A), J6.A4 (VBUS), J6.A9 (VBUS), J6.B4 (VBUS), J6.B9 (VBUS)
unnamed: D6.2 (A), J2.A4 (VBUS), J2.A9 (VBUS), J2.B4 (VBUS), J2.B9 (VBUS)
unnamed: J2.A5 (CC1), R20.1
unnamed: J2.B5 (CC2), R21.2
unnamed: J6.A5 (CC1), R52.1
unnamed: J6.B5 (CC2), R53.2
unnamed: JP1.1 (A), JP2.1 (A), JP43.2 (B), JP44.2 (B), U13.6 (2IN-)
unnamed: JP1.2 (B), R23.1
unnamed: C3.1, JP2.2 (B)
unnamed: JP3.2 (B), U8.8 (VOUT), U13.3 (1IN+)
unnamed: JP4.2 (B), U1.8 (VOUT), U19.3 (1IN+)
unnamed: JP6.1 (A), R2.2
unnamed: JP7.2 (B), U2.8 (VOUT), U25.3 (1IN+)
unnamed: JP9.1 (A), R18.2
unnamed: JP10.2 (B), U12.8 (VOUT), U22.3 (1IN+)
unnamed: JP11.2 (B), JP12.2 (B), JP49.1 (A), JP50.1 (A), U22.6 (2IN-)
unnamed: JP12.1 (A), R24.2
unnamed: JP13.2 (B), U11.8 (VOUT), U21.3 (1IN+)
unnamed: JP14.2 (B), JP15.2 (B), JP51.1 (A), JP52.1 (A), U21.6 (2IN-)
unnamed: JP15.1 (A), R26.2
unnamed: JP16.2 (B), U7.8 (VOUT), U29.3 (1IN+)
unnamed: JP17.2 (B), JP18.2 (B), JP53.1 (A), JP54.1 (A), U29.6 (2IN-)
unnamed: JP18.1 (A), R28.2
unnamed: JP19.2 (B), U9.8 (VOUT), U30.3 (1IN+)
unnamed: JP20.2 (B), JP21.2 (B), JP55.1 (A), JP56.1 (A), U30.6 (2IN-)
unnamed: JP21.1 (A), R30.2
unnamed: JP22.2 (B), U18.5 (VOUT), U31.3 (1IN+)
unnamed: JP23.2 (B), JP24.2 (B), JP57.1 (A), JP58.1 (A), U31.6 (2IN-)
unnamed: JP24.1 (A), R32.2
unnamed: JP25.2 (B), U10.5 (VOUT), U32.3 (1IN+)
unnamed: JP26.2 (B), JP27.2 (B), JP59.1 (A), JP60.1 (A), U32.6 (2IN-)
unnamed: JP27.1 (A), R34.2
unnamed: JP28.2 (B), U17.5 (VOUT), U33.3 (1IN+)
unnamed: JP29.2 (B), JP30.2 (B), JP61.1 (A), JP62.1 (A), U33.6 (2IN-)
unnamed: JP30.1 (A), R36.2
unnamed: JP31.2 (B), U15.5 (VOUT), U34.3 (1IN+)
unnamed: JP32.2 (B), JP33.2 (B), JP63.1 (A), JP64.1 (A), U34.6 (2IN-)
unnamed: JP33.1 (A), R38.2
unnamed: JP34.2 (B), U14.5 (VOUT), U35.3 (1IN+)
unnamed: JP35.2 (B), JP36.2 (B), JP65.1 (A), JP66.1 (A), U35.6 (2IN-)
unnamed: JP36.1 (A), R40.2
unnamed: JP37.2 (B), U16.5 (VOUT), U36.3 (1IN+)
unnamed: JP38.2 (B), JP39.2 (B), JP67.1 (A), JP68.1 (A), U36.6 (2IN-)
unnamed: JP39.1 (A), R42.2
unnamed: JP40.2 (B), U20.5 (VOUT), U37.3 (1IN+)
unnamed: JP41.2 (B), JP42.2 (B), JP69.1 (A), JP70.1 (A), U37.6 (2IN-)
unnamed: JP42.1 (A), R44.2
unnamed: JP44.1 (A), R22.2
unnamed: JP5.2 (B), JP6.2 (B), JP45.1 (A), JP46.1 (A), U19.6 (2IN-)
unnamed: JP45.2 (B), R11.1
unnamed: C60.1, JP46.2 (B)
unnamed: JP8.2 (B), JP9.2 (B), JP47.1 (A), JP48.1 (A), U25.6 (2IN-)
unnamed: JP47.2 (B), R19.1
unnamed: C61.1, JP48.2 (B)
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
